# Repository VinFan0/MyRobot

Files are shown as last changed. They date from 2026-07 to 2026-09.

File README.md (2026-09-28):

# MyRobot

## Table of Contents
1. [Introduction](#introduction)
2. [To-Do List](#to-do-list)
3. [Dependencies](#dependency-libraries)
4. [Control Modes](#control-modes)
5. [Hardware Requirements](#hardware-requirements)
    - [Microcontroller](#microcontroller)
    - [Motors](#motors)
    - [User Interface](#user-interface)
    - [Power Train](#power-train)
    - [Body](#myrobot-body)

## Introduction

ESP32 Companion Robot, structured around a ESP32-WROOM-32 Development Kit. I built this project as an opportunity to continue using skills obtained through school, and as a potential resume-supporting item.

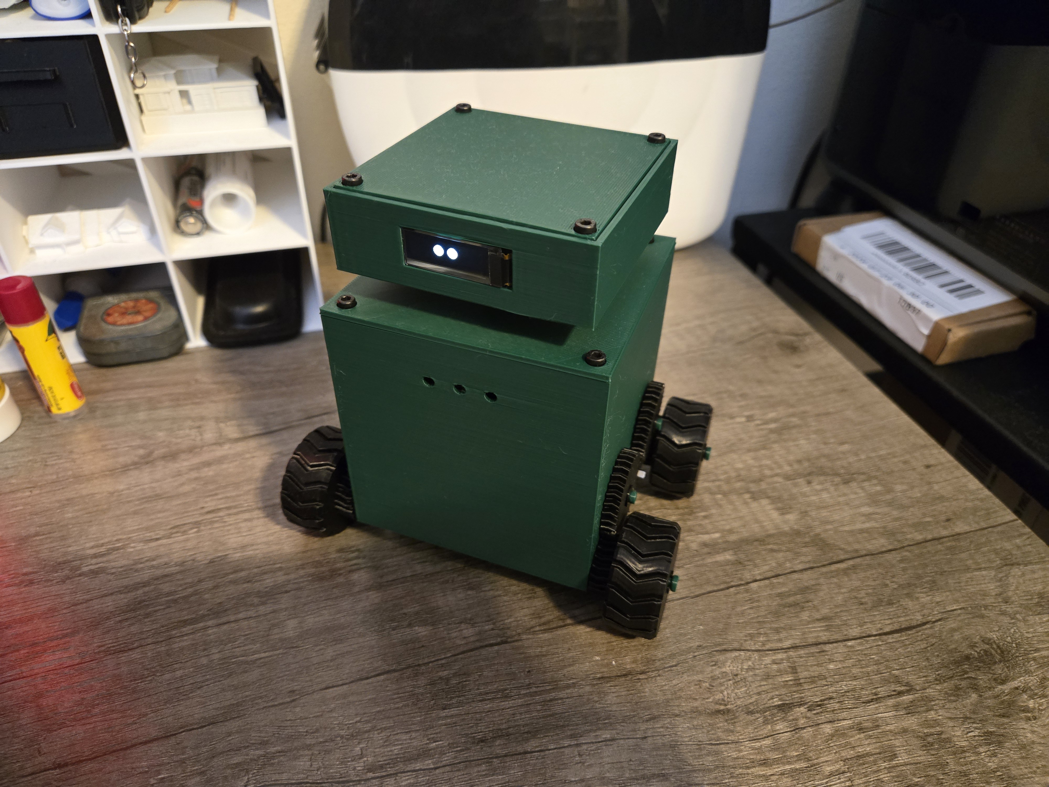
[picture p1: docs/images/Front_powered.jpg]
MyRobot V1


### See Also
[Custom PCB Design](https://www.github.com/VinFan0/MyRobot_PCB)

## To-Do List
- Design body for PCB R1.1-A
    - Make head smaller for screw access
- Get video of operation
- Wire up status LEDs
- Write status LED code
- Replace high-torque drive motors
- Troubleshoot servo "sticking" while turning
- Implement working advanced controls

## Dependency Libraries
The following libraries must be installed in order to build the project:
- BluetoothSerial
- SPI
- math
- Adafruit\_GFX
- Adafruit\_SSD1306
- ESP32Servo

## Control Modes
MyRobot is controlled via Bluetooth with the BT Car Controller-Arduino/ESP mobile application, available from the [Google Play Store](https://play.google.com/store/apps/details?id=com.giristuido.bluetooth.car.controller&hl=en_US). The application offers both **Basic** and **Advanced** control modes. 

**Basic** mode consists of 4 main buttons for control: Forward, Backward, Right, Left. Pressing a button, or a valid combination, sends a single, corresponding, character over bluetooth.

The MyRobot\_Basic\_Control branch will be built to allow the basic mode controls. 

**Advanced** mode provides two joy-stick style controls. One provides a spectrum for forward and reverse, while the other controls right and left. When a stick is moved to a location, 6 individual characters are sent in the following pattern.

- Throttle Character ('F' or 'B')
- Throttle value tens digit
- Throttle value ones digit
- Direction character ('R' or 'B')
- Direction value tens digit
- Direction value ones digit

As an example, if the throttle stick is set to forward with a magnitude of 50, and the direction stick is on left with magnitude 10, the series of Bluetooth characters will be `F 5 0 L 1 0`.

## Hardware Requirements

The first revision (V1) of MyRobot is built using perfboard, wires, and separate breakout boards for each hardware peripheral. For V2, I've developed a custom PCB. The PCB implements the same features of battery charging/protection, multiple voltage levels, and interface for connecting the peripherals. The PCB design can be found in a separate GitHub repository: [MyRobot\_PCB](https://www.github.com/VinFan0/MyRobot_PCB).

### Microcontroller
I used a [DOIT ESP32 DevKit V1](https://embedded-systems-design.github.io/overview-of-the-esp32-devkit-doit-v1/) for the MyRobot project. This decision was driven primarily by how many pins would be required to connect each of the peripherals. The project is not incredibly intensive on storage, so no additional flash should be required.

All current versions of MyRobot utilize the same developement board. This is to retain easy access to the microcontroller for development and troubleshooting as the board connects via header pins instead of being soldered to the PCB.

### Motors
MyRobot utilizes 2, 2700 RPM, DC motors for drive control, and a servo motor for head movement.
- DC Motors
    - [RF-500TB-18280 Mini DC Motor](https://www.amazon.com/RF-500TB-18280-Electric-1-5V-5V-2700RPM-Diameter/dp/B09N2PPWCW?th=1)
    - 1.5V-5V, 2700RPM.
- Servo
    - [DFROBOT DS-S006L](https://www.dfrobot.com/product-2120.html)
    - 9g, 180&deg;

### User Interface
- [Android BT Car Controller](https://play.google.com/store/search?q=bt%20car%20controller&c=apps&hl=en_US)
- [Digilent PMOD OLED Module](https://digilent.com/reference/pmod/pmodoled/start)
    - SSD1306 primary IC
    - 128x32 pixels
    - SPI
- **TODO** LEDs
    - Three 3mm colored LEDs to provide status information

### Power Train
**(REV 1, Pre Custom PCB)**
- [1S 2000mAh LiPo battery](https://www.amazon.com/Winfox-Rechargeable-Connector-Bluetooth-Portable/dp/B0GDQ7Q58F)
- [HiLetgo TP4056 LiPo Charger Module](https://www.amazon.com/dp/B07PKND8KG)
- [Ferwooh MT3608 Variable Boost Converter](https://www.amazon.com/dp/B0D17PHDSD)

*Breakout boards used in the power train are replaced with respective ICs on the PCB*

### MyRobot Body
MyRobot is housed in a 3D printed enclosure. The body utilizes M3x6 screws and heat-set inserts to hold everything in place (The servo motor has smaller M2 screws connecting the servo horn to the head enclosure). The body includes spaces to hold the electronics and drive-gear assemblies in place. 

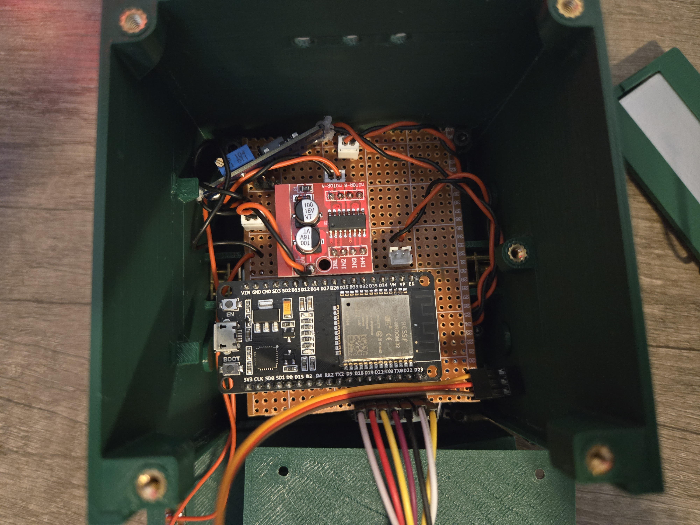
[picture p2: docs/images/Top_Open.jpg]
Head and top cover removed


Access to the USB-C battery charging port was neglected in V1 of the body, so the back panel must be removed to charge the battery.
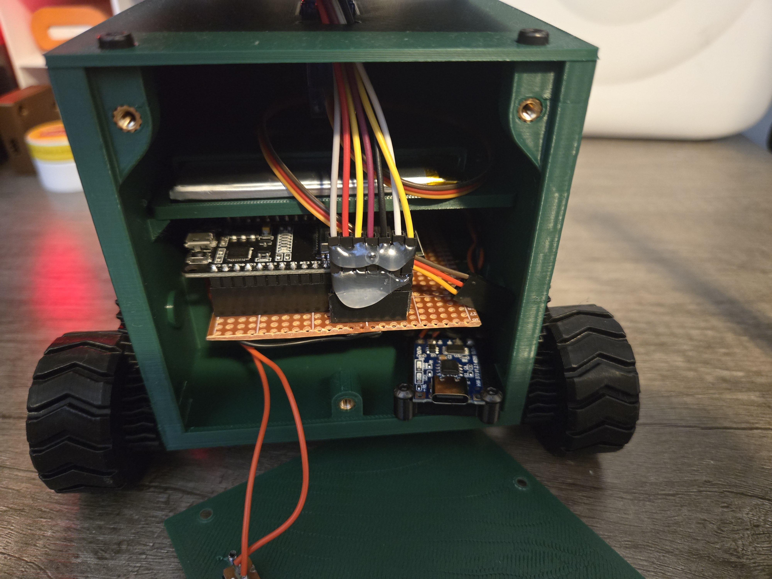
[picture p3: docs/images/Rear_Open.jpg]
Rear panel removed


The top and bottom panels can both be removed for easy access to the electronics.
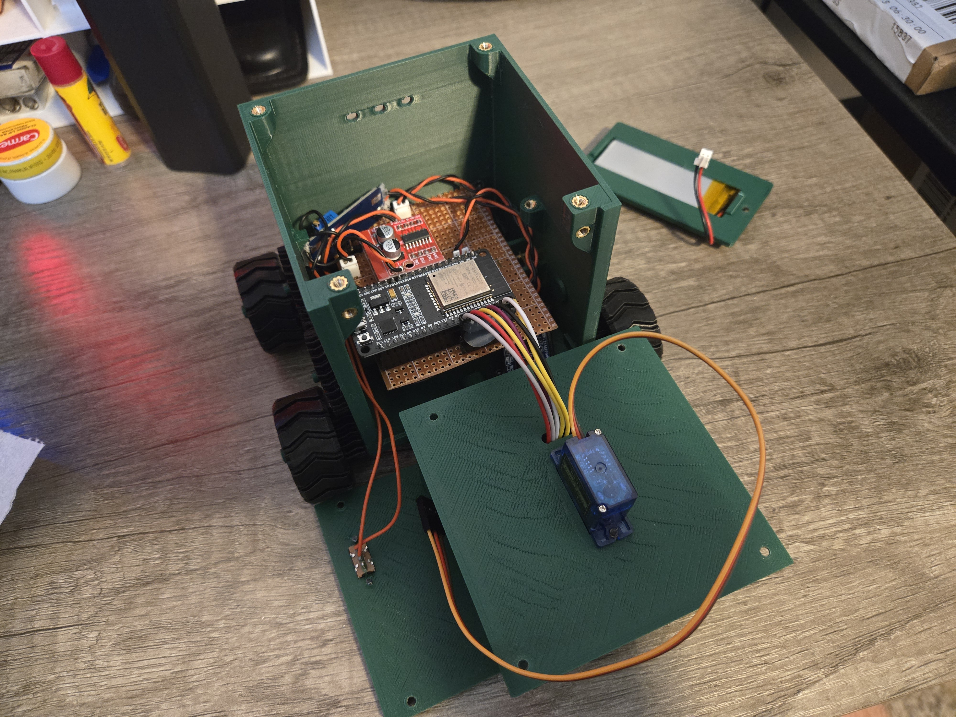
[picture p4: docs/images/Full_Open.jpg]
All panels removed


All photos and videos obtained during the making of MyRobot can be found under `docs/images/`.

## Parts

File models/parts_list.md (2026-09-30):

# MyRobot 3D Print Parts List
## Ryan Beck
### 9/29/2026

All 3D print files designed in [onshape](https://www.onshape.com/en/).

## Files
Model files are divided into 3 sections:
* Chasis
* Drive Train
* Electronics

The models in each section, along with their required quantities, are listed below.

**Chasis**
*Print one of each item in the chasis.*
* Back Door
* Body Lid
* Body
* Head Lid
* Head
* Weight Holder

**Drive Train**
* 2x Drive Gear Washer
* 2x Drive Gear 
* 4x Intermediate Axle
* 4x Intermediate Gear Washer
* 4x Intermediate Gear
* 8x Snap Ring
* 4x Wheel Axle
* 2x Wheel Gear Left
* 2x Wheel Gear Right
* 4x Wheel Gear Washer

**Electronics**
*Print one of each item in the electronics.*
* Battery Casing
* Battery Clip

## Print Settings
I printed all of the parts with the following general settings:
* PLA (specifically esun PLA+ that I got on sale)
* 0.16mm layer height
* 2 wall loops (not required, but could bump to 3 for added weight and strength)
* 15% sparse infill
* All parts are modeled to not require supports (Axle ends may be questionable, but as long as the clip will go in it's fine.)

I've also included my OrcaSlicer project will all the required parts ready in 3 separate build plates.

TODO: Record build video

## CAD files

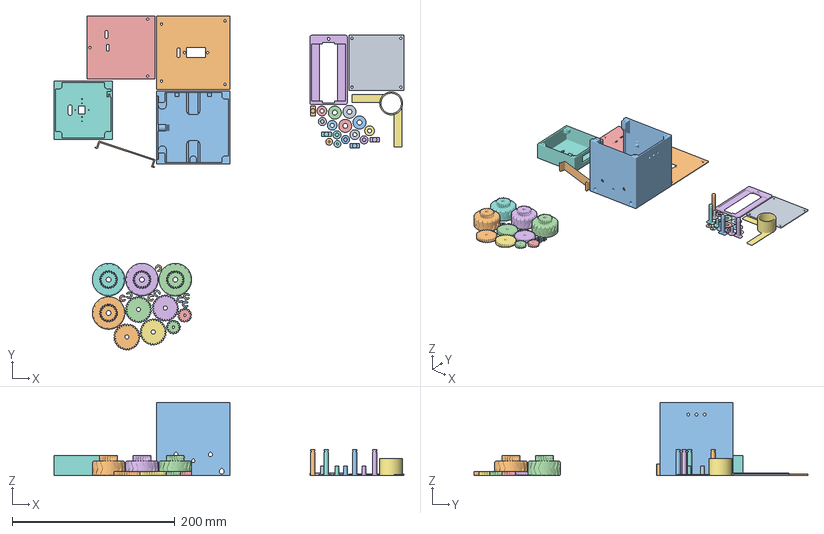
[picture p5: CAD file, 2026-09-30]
models/MyRobot_PrintingProject.3mf
429.8 x 410.2 x 90.0 mm
Body - Head Lid.stl
Body - Body Lid.stl
Body - Body.stl
Assembly 1 - Spur gear (20 teeth)-Mirrored.stl
Body - Back Door.stl
Assembly 1 - Battery Casing.stl
Body - Weight Holder.stl
Body - Head.stl
Assembly 1 - Part 7.stl x 3
Electronics - Battery Clip.stl
Assembly 1 - Drive Gear Washer.stl
Assembly 1 - Spur gear (20 teeth).stl
Assembly 1 - Part 9.stl x 3
Assembly 1 - Wheel Gear Right-Mirrored.stl
Assembly 1 - Intermediate Gear Washer.stl
Assembly 1 - Wheel Gear Right.stl
Assembly 1 - Intermediate Gear Right.stl
Assembly 1 - Intermediate Gear Right-Mirrored.stl
Assembly 1 - Spur gear (30 teeth).stl
Assembly 1 - Indermediate Axle.stl x 4
Assembly 1 - Spur gear (30 teeth)-Mirrored.stl
Assembly 1 - Drive Gear Right-Mirrored.stl
Assembly 1 - Drive Gear Right.stl
Assembly 1 - Snap Ring.stl x 8
Assembly 1 - Wheel Axle.stl x 4
Assembly 1 - Drive Gear Washer (1).stl x 2

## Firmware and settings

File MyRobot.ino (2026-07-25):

#include "bluetooth.h"
#include "motors.h"
#include "oled.h"
#include "servo.h"

bt_commands_t bt_readings;

// ============================================================
void setup() {
  Serial.begin(115200);
  delay(500); 
  // oled_init();
  // servo_init();
  bluetooth_init();
  motors_init();
}

// ============================================================
void loop() {
  // oled_update();
  // servo_update();
  bluetooth_update(&bt_readings);
  motors_update(&bt_readings);
  delay(100);
}

// ============================================================

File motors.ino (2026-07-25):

#include "motors.h"

void motors_init(void) {
  pinMode(LED_BUILTIN, OUTPUT);
  
  for(int i=0; i<NUM_MOTORS;) {
    ledcAttach(MOTORS[i].forward_pin, MOTOR_PWM_FREQ, MOTOR_PWM_BITS);
    ledcAttach(MOTORS[i].reverse_pin, MOTOR_PWM_FREQ, MOTOR_PWM_BITS);
    motor_stop(i);
    i++;
  }
}

void motors_update(bt_commands_t *bt_readings) {

  // TODO: Scale motor inputs
  // Max value from application is 99 + 60 = 159 (positive or negative)

  /*
  Right Motor
  ------------
  +Throttle(Forward)
    +Yaw(Right)
      Throttle - Yaw
    -Yaw(Left)
      Throttle - Yaw
    
    ** Throttle - Yaw**

  -Throttle(Reverse)
    +Yaw(Right)
      Throttle - Yaw
    -Yaw(Left)
      Throttle - Yaw

    ** Throttle - Yaw**

  **********************************
  +Throttle ---> Throttle - Yaw
  -Throttle ---> -(Throttle - Yaw)
  **********************************
  */
  float right_motor_command = abs(bt_readings->throttle_val) - bt_readings->yaw_val;

  // Serial.print("Right Motor Value: ");
  if (bt_readings->throttle_val > 0) { // +Throttle (Forward)
    motor_forward(MOTOR_RIGHT_IDX, right_motor_command);
    // Serial.print("Forward: ");

  } else if (bt_readings->throttle_val < 0) {  // -Throttle (Reverse)
    motor_reverse(MOTOR_RIGHT_IDX, right_motor_command);
    // Serial.print("Reverse: ");

  } else {  // 0 Throttle
    if (bt_readings->yaw_val > 0) { // +Yaw (Right)
      // Serial.print("Turn Right: ");
      motor_reverse(MOTOR_RIGHT_IDX, bt_readings->yaw_val);

    } else if (bt_readings->yaw_val < 0) { // -Yaw (Left)
      // Serial.print("Turn Left: ");
      motor_forward(MOTOR_RIGHT_IDX, abs(bt_readings->yaw_val));

    } else { // Motors Stop
      // Serial.print("Stop Motors");
      motor_stop(MOTOR_RIGHT_IDX);
    }
  }
  // Serial.println(right_motor_command);
  
}

void motor_forward(int motor_idx, int speed) {
  speed = constrain(map(speed, 39, 159, MOTOR_PWM_MIN, MOTOR_PWM_MAX), MOTOR_PWM_MIN, MOTOR_PWM_MAX);
  Serial.print("Forward: ");
  Serial.println(speed);
  ledcWrite(MOTORS[motor_idx].forward_pin, speed);
  ledcWrite(MOTORS[motor_idx].reverse_pin, 0);
}

void motor_reverse(int motor_idx, int speed) {
  speed = constrain(map(speed, 39, 159, MOTOR_PWM_MIN, MOTOR_PWM_MAX), MOTOR_PWM_MIN, MOTOR_PWM_MAX);
  Serial.print("Reverse: ");
  Serial.println(speed);
  ledcWrite(MOTORS[motor_idx].forward_pin, 0);
  ledcWrite(MOTORS[motor_idx].reverse_pin, speed);
}

void motor_stop(int motor_idx) {
  ledcWrite(MOTORS[motor_idx].forward_pin, 0);
  ledcWrite(MOTORS[motor_idx].reverse_pin, 0);
}

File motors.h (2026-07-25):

#include "bluetooth.h"

#ifndef MOTORS_H
#define MOTORS_H

#define NUM_MOTORS 1
#define MOTOR_RIGHT_IDX 0
#define MOTOR_LEFT_IDX 1

#define MOTOR_PWM_FREQ    5000 // 5 KHz
#define MOTOR_PWM_BITS    8    // 0-127
#define MOTOR_PWM_MAX     250
#define MOTOR_PWM_MIN     190

typedef struct motor_s{
  const int forward_pin = NULL;
  const int reverse_pin = NULL;
} motor_t;

motor_t MOTORS[] = {
  {33,32} // Right Motor Forward 33, Reverse 32
};

typedef struct motor_commands_s{
  float throttle_val;
  float yaw_val;
} motor_commands_t;

motor_commands_t motor_commands;

void motors_init(void);
void motors_update(bt_commands_t *bt_readings);
void motor_forward(int motor_idx, int speed);
void motor_reverse(int motor_idx, int speed);
void motor_stop(int motor_idx);

#endif // MOTORS_H

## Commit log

2026-07-25 feat: bluetooth motor control
    Currently, bluetooth commands sent from the mobile application
    are just printed to the serial terminal. It also only accepts
    simple control mode with discrete characters and no range values.
    Add code to parse advanced mode bluetooth data and and store it in
    a global struct type, bt_readings_t.
    Also, the test motor is currently controlled by 2 push buttons for
    forward and reverse. Add code to enterpret the bt_readings_t struct
    and send PWM signals to the motors.
    [MyRobot.ino, bluetooth.ino, motors.h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]
2026-09-23 docs(readme): fix readme errors
    - Fix table of contents links going to top of page
    - Add introduction title for TOC
    - Fix nested list items showing un-nested after a new line
    - Fix hyper-links to PCB repo
2026-09-23 docs(readme): fix TODO bolding
    The TODO tag on the LEDs is italicised instead of bolded.
2026-09-23 docs(readme): make head smaller to-do
    Add a to-do item to make the head 3D model smaller for
    easier access to the top body screws
2026-09-28 docs(README): Update To-Do after PCB R1.1-A
    The first custom PCB has been delivered and functions properly.
    Reorganize the To-Do list for the code body files to reflect my
    priorities.
2026-09-30 files(ignore): create gitignore
    After exporting all of the 3D print files into the repo, I decided
    I don't want to upload each stl into github.
    Create a .gitignore file and insert *.stl to ignore these files.
2026-09-30 files(models): add models .zip, project, and .md
    Add a .zip archive with all the .stl files, along with the
    OrcaSlicer project. Include a .md file with an explanation
    of what parts are required, and how many.
    [MyRobot_PrintingProject.3mf]
